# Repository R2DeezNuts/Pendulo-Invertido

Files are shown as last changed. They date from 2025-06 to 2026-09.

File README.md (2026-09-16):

# Péndulo invertido: control PID e interfaz web

Sistema de control PID para estabilizar un péndulo invertido con un ESP32. Incluye una interfaz web para ajustar los parámetros, telemetría y rutinas de calibración.

## Características

- Control PID a 100 Hz.
- Ajuste remoto de Kp, Ki, Kd, setpoint y offset.
- Calibración del ángulo cero.
- Desactivación automática cuando detecta una caída.
- Telemetría del estado del sistema.
- Anti-windup para limitar la acumulación del término integral.

## Hardware

- **Microcontrolador:** ESP32
- **Sensor inercial:** MPU6050 (acelerómetro y giroscopio)
- **Actuadores:** dos motores DC con puente H

### Conexiones GPIO

#### MPU6050 (I2C)

| Señal | GPIO |
|---:|:----:|
| SDA | 21 |
| SCL | 22 |

#### Motores (puente H)

| Motor | Señal | GPIO |
|---:|:-----:|
| A | PWMA  | 26 |
| A | AIN1  | 2 |
| A | AIN2  | 0 |
| B | PWMB  | 25 |
| B | BIN1  | 16 |
| B | BIN2  | 17 |

## Puesta en marcha

1. Conéctate a la red WiFi **RobotAP** (contraseña: 12345678).
2. Abre http://192.168.4.1 en el navegador.
3. Con el robot en posición vertical, calibra el ángulo cero antes de activar los motores.
4. Ajusta los parámetros PID desde la interfaz y activa el control.

Péndulo invertido en funcionamiento

## Parámetros ajustables

| Parámetro | Descripción |
|---:|---|
| **Kp, Ki, Kd** | Constantes del controlador PID |
| **Setpoint** | Ángulo objetivo, en grados |
| **Offset** | Ajuste fino para la calibración |

## Protección y arquitectura

La protección desactiva el control cuando el ángulo supera los 30° durante más de un segundo. El control se ejecuta en una tarea de FreeRTOS a 100 Hz; el servidor web permite consultar el estado y cambiar los parámetros; y un filtro complementario combina el acelerómetro y el giroscopio para estimar el ángulo.

## Uso recomendado

Coloca el robot en vertical, calibra el sensor y empieza con valores PID conservadores. Activa los motores mientras observas la telemetría y ajusta el setpoint y el offset de forma gradual.

Si entra en modo de protección, revisa la calibración, el sentido de giro, la saturación del control y las vibraciones o el ruido del MPU6050.

Detalle del péndulo invertido

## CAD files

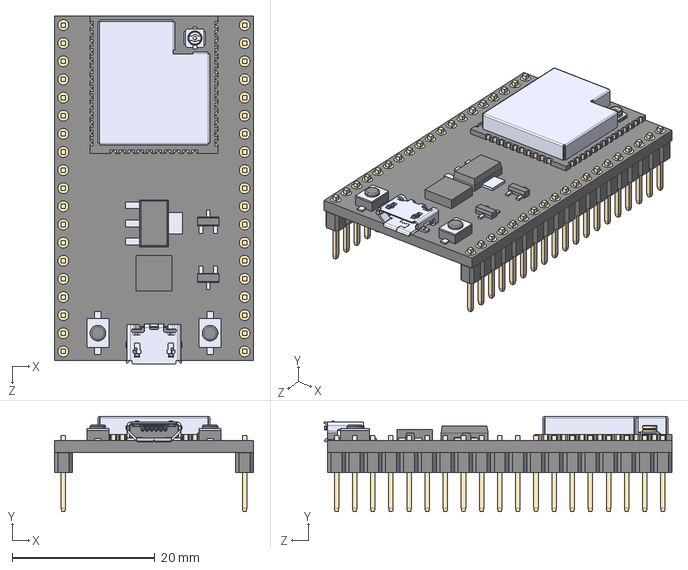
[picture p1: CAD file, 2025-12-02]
PCB/ESP32-DEVKITC-32UE/ESP32-DEVKITC-32UE.step
27.9 x 13.4 x 48.8 mm

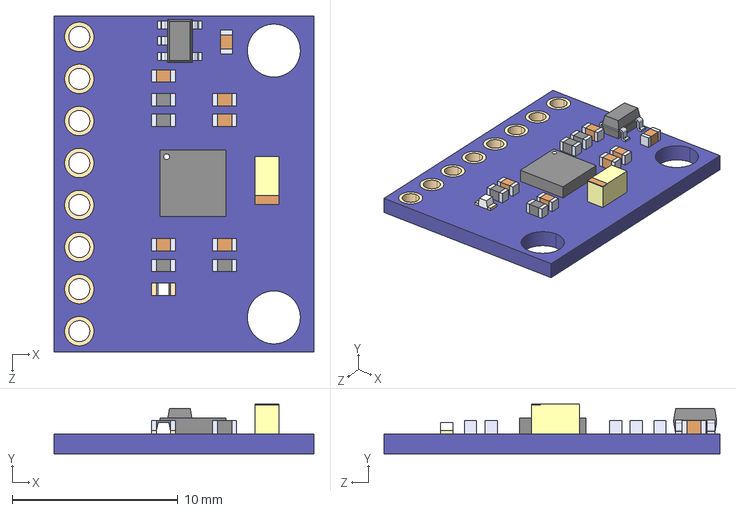
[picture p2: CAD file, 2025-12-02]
PCB/GY-521/GY-521.step
15.7 x 3.00 x 20.3 mm

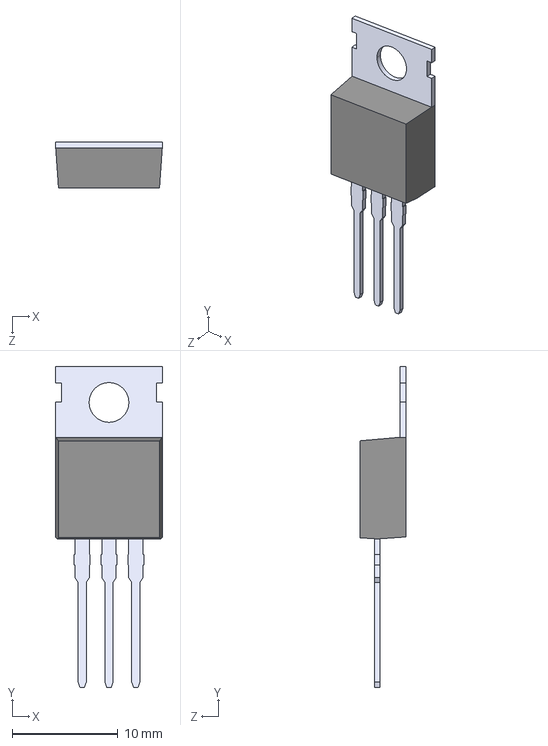
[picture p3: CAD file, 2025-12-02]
PCB/LM7805CT_NOPB.step
10.2 x 30.3 x 4.35 mm

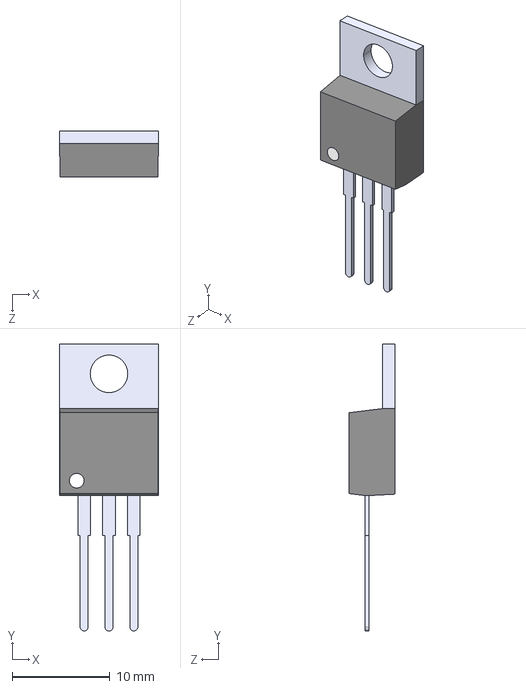
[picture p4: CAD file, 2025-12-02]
PCB/LM7805CT_NOPB/LM7805CT_NOPB.step
10.2 x 29.3 x 4.70 mm

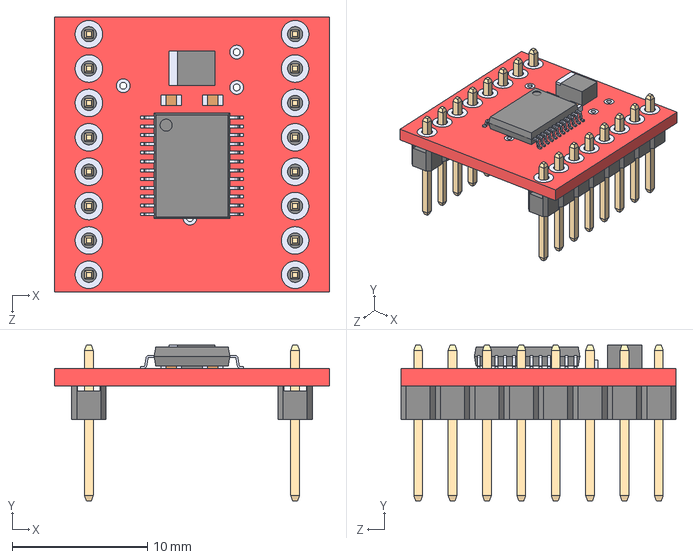
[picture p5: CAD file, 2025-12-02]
PCB/ROB-14450/ROB-14450.step
20.3 x 11.5 x 20.3 mm

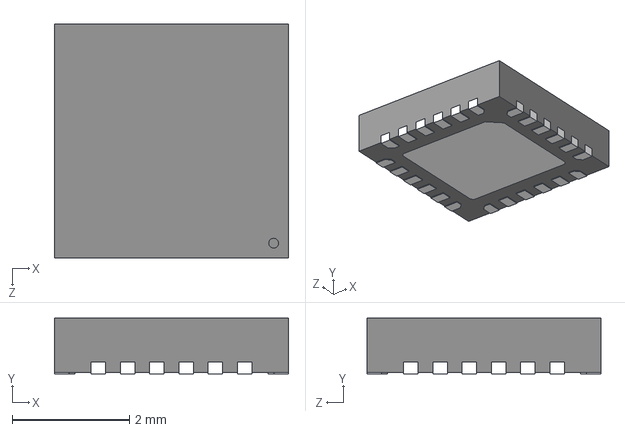
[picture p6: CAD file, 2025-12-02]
PCB/MPU-6050-A.step
4.00 x 0.95 x 4.00 mm

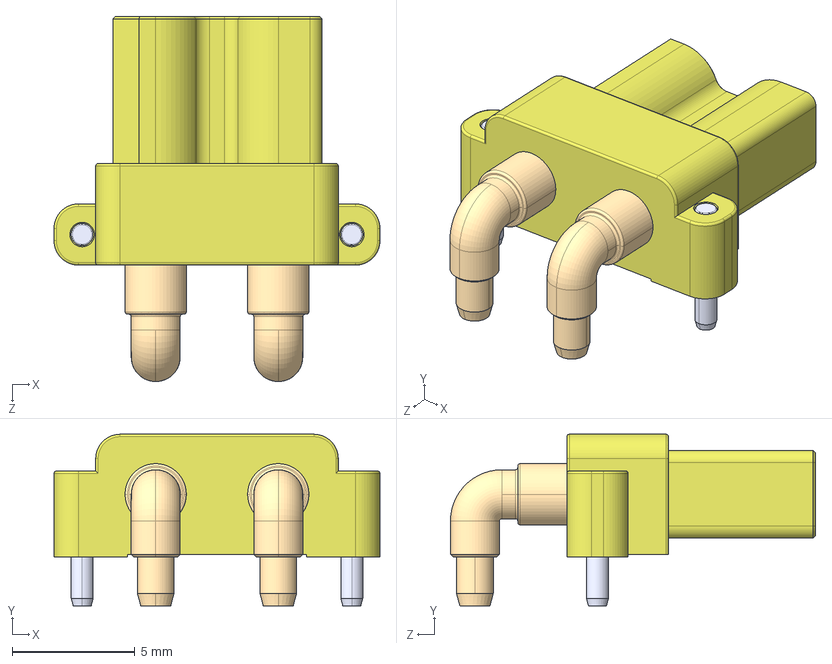
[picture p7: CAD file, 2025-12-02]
PCB/XT30PW-F.step
13.3 x 7.00 x 14.9 mm

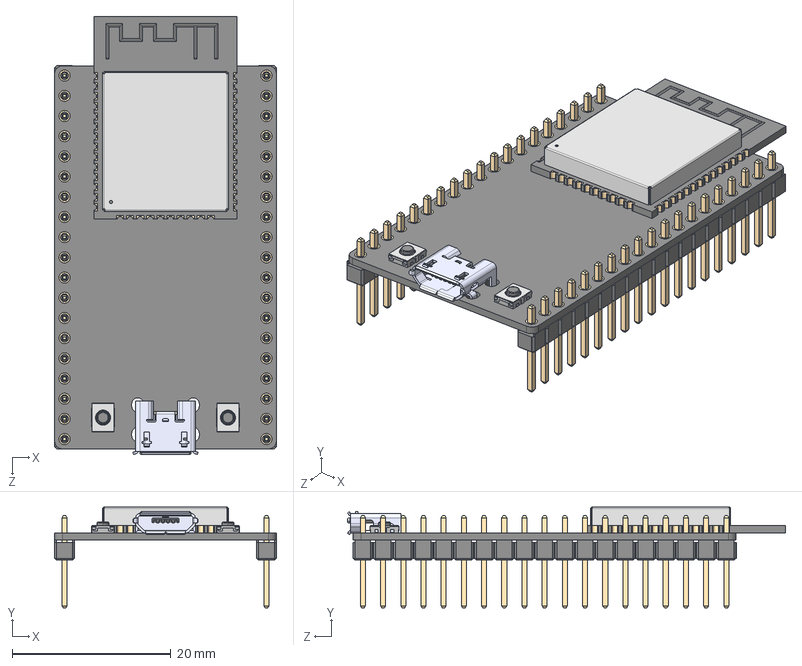
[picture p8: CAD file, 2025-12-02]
PCB/ESP32-DEVKITC-32D.step
27.9 x 12.7 x 55.1 mm
board
header x 2
ESP32-WROOM-32D
micro usb
button x 2

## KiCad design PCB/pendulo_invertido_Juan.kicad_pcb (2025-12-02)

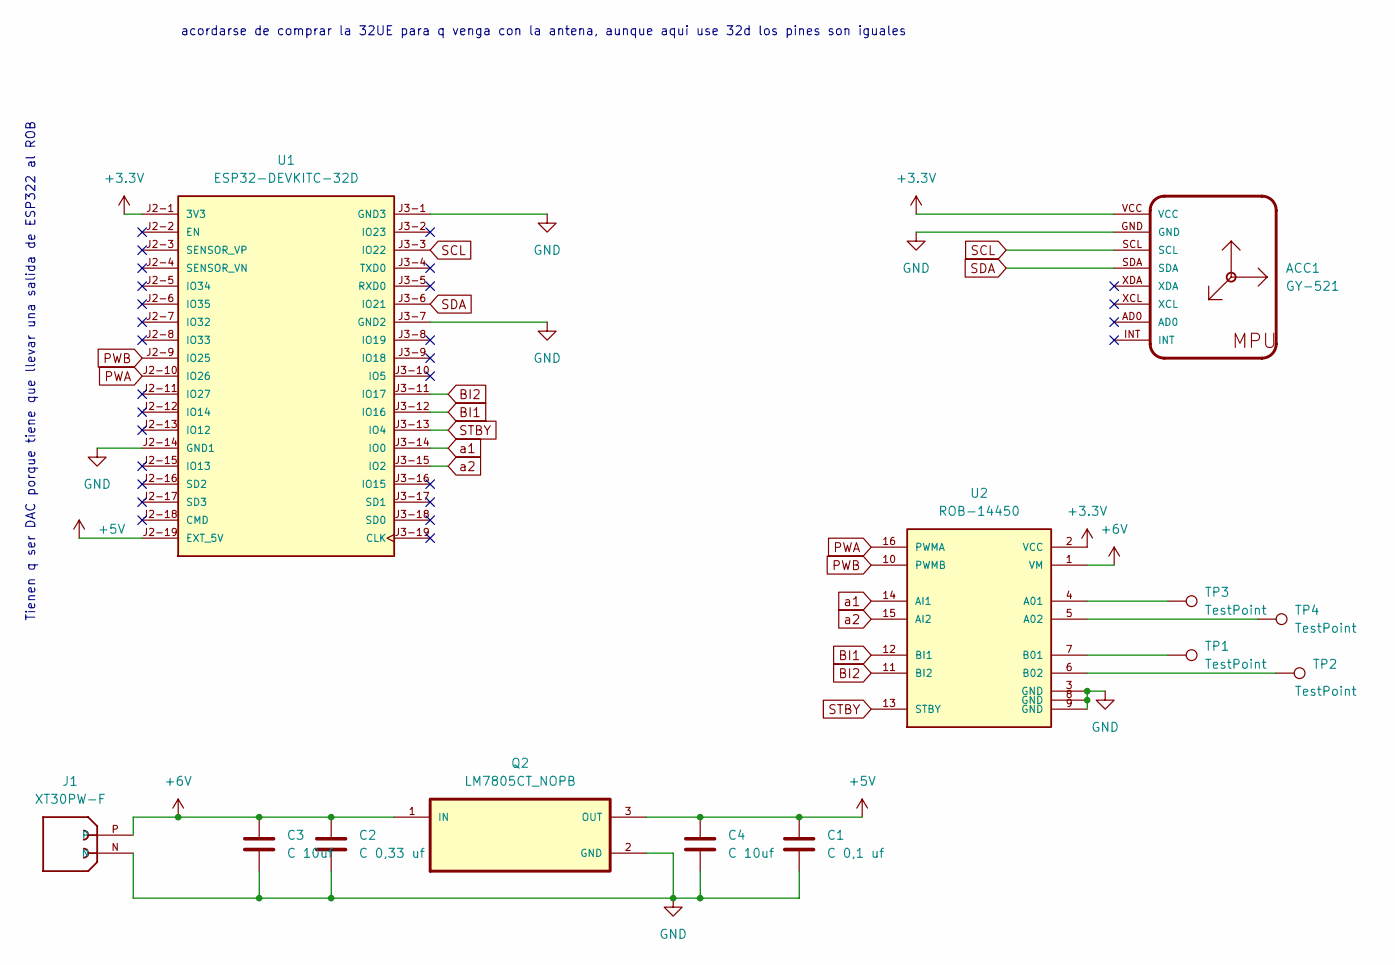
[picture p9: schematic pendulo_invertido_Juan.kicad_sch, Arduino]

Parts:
ACC1: GY-521
C1: C 0,1 uf; C_Disc_D4.3mm_W1.9mm_P5.00mm
C2: C 0,33 uf; C_Disc_D4.3mm_W1.9mm_P5.00mm
C3, C4: C 10uf; CP_Radial_D4.0mm_P2.00mm
J1: XT30PW-F; AMASS_XT30PW-F; PARTREV 1.2
Q2: LM7805CT_NOPB; TO254P1054X470X1955-3
TP1, TP2, TP3, TP4: TestPoint; TestPoint_THTPad_D2.0mm_Drill1.0mm
U1: ESP32-DEVKITC-32D; MODULE_ESP32-DEVKITC-32D; PARTREV V4
U2: ROB-14450; MODULE_ROB-14450; PARTREV 11-13-17

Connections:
+3.3V: ACC1.VCC, U1.J2-1 (3V3), U2.2 (VCC)
+5V: C1.1, C4.1, Q2.3 (OUT), U1.J2-19 (EXT_5V)
+6V: C2.1, C3.1, J1.P, Q2.1 (IN), U2.1 (VM)
BI1: U1.J3-12 (IO16), U2.12 (BI1)
BI2: U1.J3-11 (IO17), U2.11 (BI2)
GND: ACC1.GND, C1.2, C2.2, C3.2, C4.2, J1.N, Q2.2 (GND), U1.J2-14 (GND1), U1.J3-1 (GND3), U1.J3-7 (GND2), U2.3 (GND), U2.8 (GND), U2.9 (GND)
unnamed: TP3.1, U2.4 (A01)
unnamed: TP4.1, U2.5 (A02)
unnamed: TP1.1, U2.7 (B01)
unnamed: TP2.1, U2.6 (B02)
PWA: U1.J2-10 (IO26), U2.16 (PWMA)
PWB: U1.J2-9 (IO25), U2.10 (PWMB)
SCL: ACC1.SCL, U1.J3-3 (IO22)
SDA: ACC1.SDA, U1.J3-6 (IO21)
STBY: U1.J3-13 (IO4), U2.13 (STBY)
a1: U1.J3-14 (IO0), U2.14 (AI1)
a2: U1.J3-15 (IO2), U2.15 (AI2)

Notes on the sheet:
Tienen q ser DAC porque tiene que llevar una salida de ESP322 al ROB
acordarse de comprar la 32UE para q venga con la antena, aunque aqui use 32d los pines son iguales

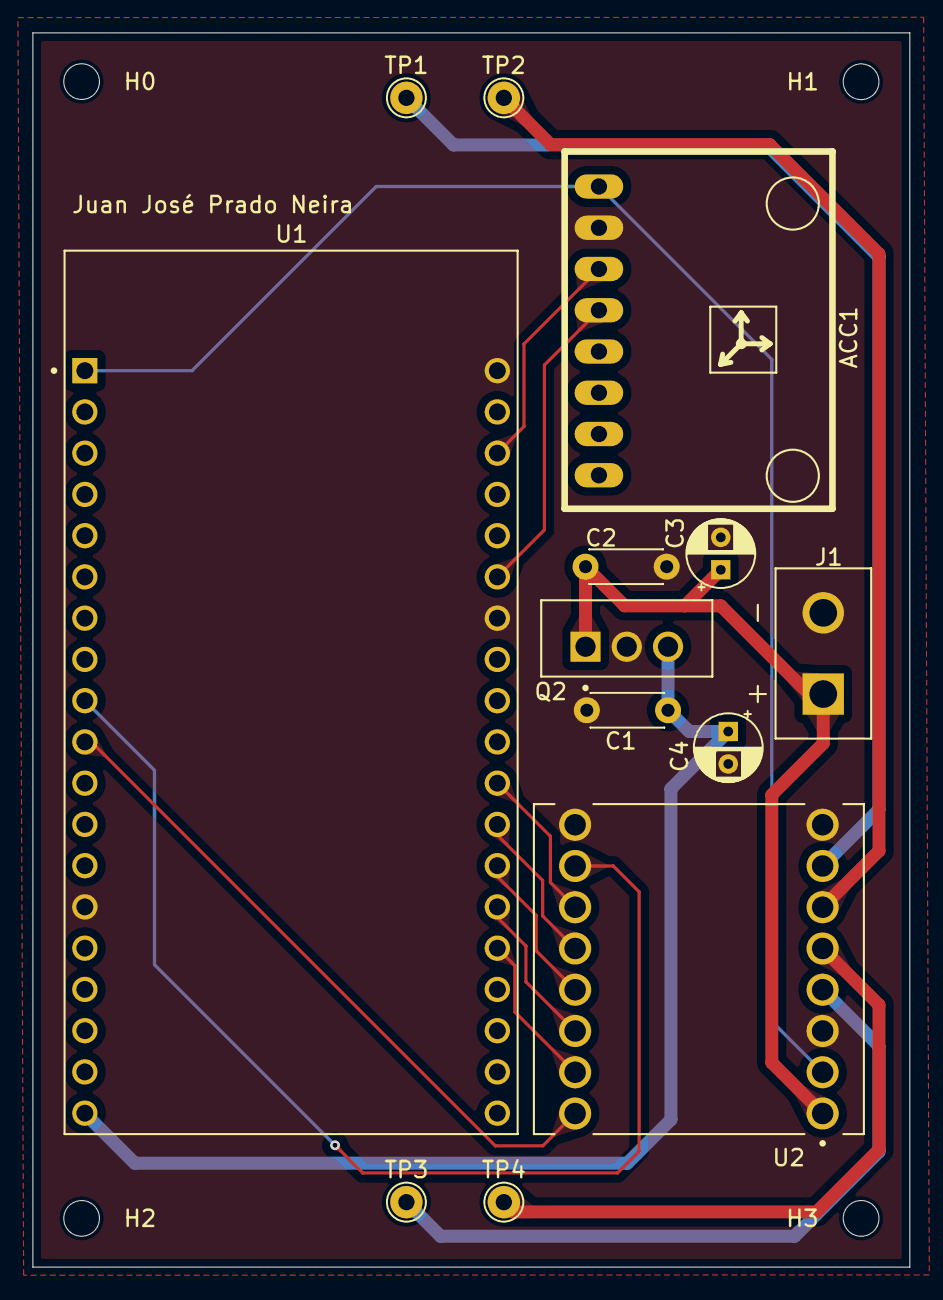
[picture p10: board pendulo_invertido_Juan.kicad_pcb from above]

Board: 2 copper layers, 54.0 x 76.0 mm, 17 parts (0 on the bottom side), 17 nets.

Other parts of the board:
H0, H1, H2, H3: MountingHole_2.2mm_M2

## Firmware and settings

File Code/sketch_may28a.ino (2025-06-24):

#include <Arduino.h>
#include <WiFi.h>
#include <WebServer.h>
#include <DNSServer.h>
#include <EEPROM.h>
#include "Wire.h"
#include "I2Cdev.h"
#include "MPU6050.h"

// --------- Pines Motores ------------
const int pinSTBY      = 4;
const int pinPWMA      = 26; // DERECHO
const int pinAIN1      = 2;  // DERECHO
const int pinAIN2      = 0;  // DERECHO
const int pinPWMB      = 25; // IZQUIERDO
const int pinBIN1      = 16; // IZQUIERDO
const int pinBIN2      = 17; // IZQUIERDO

// --------- Variables MPU y filtro ---------
MPU6050 mpu;
int16_t ax, ay, az, gx, gy, gz;
float ang_x = 0, ang_x_prev = 0, accel_ang_x = 0;
float dt = 0;
unsigned long calibrateTime = 0;
float ANGLE_OFFSET = 0;
const float alpha = 0.995;

// --------- PID ---------
double setpoint = 1.0;
double output = 0.0;
double Kp = 20.0, Ki = 0.3, Kd = 0.3;
double integral = 0.0, derivative = 0.0, previous_error = 0.0;

// --------- Anti-windup PID ---------
const double integral_max = 200;
const double integral_min = -200;

// --------- Seguridad (caída, autoparado) ---------
const float MAX_ANGLE = 30.0; // grados
const unsigned long FALL_TIMEOUT = 1000; // ms
unsigned long fallStartTime = 0;
bool fallen = false;

// --------- Control Task ---------
const unsigned long CONTROL_PERIOD_MS = 10; // 10ms = 100Hz
unsigned long lastControlTime = 0;

// --------- Estado motores ---------
bool motorsEnabled = false;

// --------- WiFi portal ---------
const char* ssid     = "RobotAP";
const char* password = "12345678";
IPAddress apIP(192, 168, 4, 1);
IPAddress netMsk(255, 255, 255, 0);
WebServer server(80);
DNSServer dnsServer;
const byte DNS_PORT = 53;

float loopFrequency = 0.0;
float ajuste_fino = 0.0;

// --------- EEPROM ---------
#define EEPROM_SIZE 32
#define ADDR_KP      0
#define ADDR_KI      4
#define ADDR_KD      8
#define ADDR_SETPT  12
#define ADDR_AJUSTE 16
#define ADDR_MAGIC  20
#define MAGIC_VALUE 0xAA55AA55

void saveParams() {
  EEPROM.put(ADDR_KP,      Kp);
  EEPROM.put(ADDR_KI,      Ki);
  EEPROM.put(ADDR_KD,      Kd);
  EEPROM.put(ADDR_SETPT,   setpoint);
  EEPROM.put(ADDR_AJUSTE,  ajuste_fino);
  EEPROM.put(ADDR_MAGIC,   MAGIC_VALUE);
  EEPROM.commit();
}

void loadParams() {
  uint32_t magic;
  EEPROM.get(ADDR_MAGIC, magic);
  if (magic == MAGIC_VALUE) {
    EEPROM.get(ADDR_KP,      Kp);
    EEPROM.get(ADDR_KI,      Ki);
    EEPROM.get(ADDR_KD,      Kd);
    EEPROM.get(ADDR_SETPT,   setpoint);
    EEPROM.get(ADDR_AJUSTE,  ajuste_fino);
    Serial.println("Parámetros PID cargados de EEPROM.");
  } else {
    Serial.println("EEPROM no inicializada, usando valores por defecto.");
  }
}

// --------- Prototipos ---------
void handleRoot();
void handleToggle();
void handleStatus();
void handleGetSettings();
void handleSetSettings();
void handleNotFound();
void handleCalibrate();
void setupWiFiPortal();
void driveMotors(int value);
void ControlTask(void * parameter);

// --------- Motores ------------
void driveMotors(int value) {
  value = constrain(value, -255, 255);
  int mag = abs(value);

  // Motor IZQUIERDO (PWMB, BIN1, BIN2)
  if (value > 0) {
    digitalWrite(pinBIN1, HIGH); digitalWrite(pinBIN2, LOW); // Adelante
  } else if (value < 0) {
    digitalWrite(pinBIN1, LOW); digitalWrite(pinBIN2, HIGH); // Atrás
  } else {
    digitalWrite(pinBIN1, HIGH); digitalWrite(pinBIN2, HIGH);
    mag = 0;
  }
  analogWrite(pinPWMB, mag);

  // Motor DERECHO (PWMA, AIN1, AIN2)
  if (value > 0) {
    digitalWrite(pinAIN1, HIGH); digitalWrite(pinAIN2, LOW); // Adelante
  } else if (value < 0) {
    digitalWrite(pinAIN1, LOW); digitalWrite(pinAIN2, HIGH); // Atrás
  } else {
    digitalWrite(pinAIN1, HIGH); digitalWrite(pinAIN2, HIGH);
    mag = 0;
  }
  analogWrite(pinPWMA, mag);
}

// --------- Handlers web ---------
void handleRoot() {
  String html = R"rawliteral(
<!DOCTYPE html>
<html>
<head>
  <meta name="viewport" content="width=device-width, initial-scale=1">
  <style>
    body { margin:0; display:flex; flex-direction:column; justify-content:center; align-items:center; height:100vh; background:#000; color:#fff; }
    button, input { font-size:1.2em; margin:5px; }
    button { padding:10px; border:none; border-radius:5px; width:80%; height:40px; }
    .on { background:#4CAF50; color:#fff; }
    .off { background:#F44336; color:#fff; }
    #controls { margin-top:20px; display:flex; flex-direction:column; align-items:center; }
    label { display:flex; justify-content:space-between; width:80%; }
    input { width:60px; }
  </style>
</head>
<body>
  <button id="btn" class="off">OFF</button>
  <button id="calibrate">Calibrar ángulo cero</button>
  <div id="status">Cargando...</div>
  <div id="controls">
    <label>Kp: <input id="Kp" type="number" step="0.1"></label>
    <label>Ki: <input id="Ki" type="number" step="0.01"></label>
    <label>Kd: <input id="Kd" type="number" step="0.1"></label>
    <label>Setpoint: <input id="Setpoint" type="number" step="0.1"></label>
    <label>Ajuste fino: <input id="Ajuste" type="number" step="0.01"></label>
    <button id="apply">Aplicar</button>
  </div>
  <script>
    const btn = document.getElementById('btn');
    const status = document.getElementById('status');
    const inpKp = document.getElementById('Kp');
    const inpKi = document.getElementById('Ki');
    const inpKd = document.getElementById('Kd');
    const inpSetpoint = document.getElementById('Setpoint');
    const inpAjuste = document.getElementById('Ajuste');
    const calibrate = document.getElementById('calibrate');

    function updateButton(s) { btn.textContent = s; btn.className = s.toLowerCase(); }
    btn.onclick = () => fetch('/toggle').then(r => r.text()).then(updateButton);

    calibrate.onclick = () => { fetch('/calibrate').then(r => r.text()).then(alert); };

    function updateStatus() {
      fetch('/status').then(r => r.text()).then(t => status.textContent = t);
    }
    setInterval(updateStatus, 500); updateStatus();

    fetch('/getsettings').then(r => r.json()).then(j => {
      inpKp.value = j.Kp;
      inpKi.value = j.Ki;
      inpKd.value = j.Kd;
      inpSetpoint.value = j.Setpoint;
      inpAjuste.value = j.Ajuste;
    });

    document.getElementById('apply').onclick = () => {
      const p = new URLSearchParams({
        Kp: inpKp.value,
        Ki: inpKi.value,
        Kd: inpKd.value,
        Setpoint: inpSetpoint.value,
        Ajuste: inpAjuste.value
      });
      fetch('/setsettings?' + p).then(r => r.text()).then(alert);
    };
  </script>
</body>
</html>
)rawliteral";
  server.send(200, "text/html", html);
}

void handleToggle() {
  bool prevMotorsEnabled = motorsEnabled;
  motorsEnabled = !motorsEnabled;
  // Si se acaba de activar, resetea PID:
  if (motorsEnabled && !prevMotorsEnabled) {
    integral = 0;
    derivative = 0;
    previous_error = 0;
  }
  server.send(200, "text/plain", motorsEnabled?"ON":"OFF");
}
void handleStatus() {
  String stat = String(motorsEnabled ? "ON" : "OFF") +
                (fallen ? " | CAIDO" : "") +
                " | Ángulo: " + String(ang_x, 2) +
                "° | Velocidad: " + String(abs(output), 0) +
                " | Loop: " + String(loopFrequency, 1) + " Hz";
  server.send(200, "text/plain", stat);
}
void handleGetSettings() {
  String json = String("{\"Kp\":") + String(Kp,2) + ",\"Ki\":" + String(Ki,2) +
                ",\"Kd\":" + String(Kd,2) + ",\"Setpoint\":" + String(setpoint,2) +
                ",\"Ajuste\":" + String(ajuste_fino,2) + "}";
  server.send(200, "application/json", json);
}
void handleSetSettings() {
  if (server.hasArg("Kp")) Kp = server.arg("Kp").toFloat();
  if (server.hasArg("Ki")) Ki = server.arg("Ki").toFloat();
  if (server.hasArg("Kd")) Kd = server.arg("Kd").toFloat();
  if (server.hasArg("Setpoint")) setpoint = server.arg("Setpoint").toFloat();
  if (server.hasArg("Ajuste")) ajuste_fino = server.arg("Ajuste").toFloat();
  saveParams();
  server.send(200, "text/plain", "Settings updated");
}
void handleNotFound() {
  server.sendHeader("Location", String("http://") + apIP.toString(), true);
  server.send(302, "text/plain", "");
}
void handleCalibrate() {
  float sum = 0;
  int N = 100;
  for (int i = 0; i < N; i++) {
    mpu.getAcceleration(&ax, &ay, &az);
    sum += atan2(ay, az) * 180.0 / PI;
    delay(5);
  }
  ANGLE_OFFSET = sum / N;
  mpu.getAcceleration(&ax, &ay, &az);
  ang_x = ang_x_prev = atan2(ay, az) * 180.0 / PI - ANGLE_OFFSET - ajuste_fino;
  integral = 0;
  derivative = 0;
  previous_error = 0;
  calibrateTime = millis();
  fallen = false;
  Serial.print("Nuevo OFFSET calculado: "); Serial.println(ANGLE_OFFSET, 2);
  server.send(200, "text/plain", "Offset calibrado. ¡Ya puedes encender los motores!");
}

void setupWiFiPortal() {
  WiFi.mode(WIFI_AP);
  WiFi.softAPConfig(apIP, apIP, netMsk);
  WiFi.softAP(ssid, password);
  dnsServer.start(DNS_PORT, "*", apIP);
  server.on("/", handleRoot);
  server.on("/toggle", handleToggle);
  server.on("/status", handleStatus);
  server.on("/getsettings", handleGetSettings);
  server.on("/setsettings", handleSetSettings);
  server.on("/calibrate", handleCalibrate);
  server.onNotFound(handleNotFound);
  server.begin();
  Serial.print("AP iniciado en: "); Serial.println(WiFi.softAPIP());
}

void setup() {
  Serial.begin(115200);
  delay(2000);

  pinMode(pinSTBY, OUTPUT);
  pinMode(pinAIN1, OUTPUT);
  pinMode(pinAIN2, OUTPUT);
  pinMode(pinBIN1, OUTPUT);
  pinMode(pinBIN2, OUTPUT);
  pinMode(pinPWMA, OUTPUT);
  pinMode(pinPWMB, OUTPUT);

  digitalWrite(pinSTBY, HIGH);

  Wire.begin();
  mpu.initialize();

  // === OFFSET CALIBRADOS MANUALMENTE ===
  mpu.setXAccelOffset(-3554);
  mpu.setYAccelOffset(5858);
  mpu.setZAccelOffset(10188);
  mpu.setXGyroOffset(-30);
  mpu.setYGyroOffset(-234);
  mpu.setZGyroOffset(-30);

  delay(1000);

  float sum = 0;
  int N = 100;
  for (int i = 0; i < N; i++) {
    mpu.getAcceleration(&ax, &ay, &az);
    sum += atan2(ay, az) * 180.0 / PI;
    delay(5);
  }
  ANGLE_OFFSET = sum / N;
  Serial.print("OFFSET calculado: "); Serial.println(ANGLE_OFFSET, 2);

  mpu.getAcceleration(&ax, &ay, &az);
  ang_x = ang_x_prev = atan2(ay, az) * 180.0 / PI - ANGLE_OFFSET;
  calibrateTime = millis();
  lastControlTime = millis();

  EEPROM.begin(EEPROM_SIZE);
  loadParams();

  setupWiFiPortal();

  // --- Iniciar la tarea de control en FreeRTOS ---
  xTaskCreatePinnedToCore(
    ControlTask,
    "ControlTask",
    4096,
    NULL,
    2,
    NULL,
    1
  );
}

void loop() {
  dnsServer.processNextRequest();
  server.handleClient();
}

// ----- Tarea de control PID, filtro, autoparado, motores -----
void ControlTask(void * parameter) {
  unsigned long lastPrint = 0;
  lastControlTime = millis();
  while (true) {
    unsigned long now = millis();
    if (now - lastControlTime >= CONTROL_PERIOD_MS) {
      dt = (now - lastControlTime) / 1000.0;
      lastControlTime = now;

      // --- Sensor MPU6050 ---
      int16_t ax_raw, ay_raw, az_raw, gx_raw, gy_raw, gz_raw;
      mpu.getAcceleration(&ax_raw, &ay_raw, &az_raw);
      mpu.getRotation(&gx_raw, &gy_raw, &gz_raw);

      // --- Remapeo de ejes ---
      ax = -ay_raw;
      ay =  ax_raw;
      az =  az_raw;
      gx = -gy_raw;
      gy =  gx_raw;
      gz =  gz_raw;

      // --- Filtro complementario ---
      accel_ang_x = atan2(ay, az) * 180.0 / PI - ANGLE_OFFSET - ajuste_fino;

      if (now - calibrateTime < 2000) {
        ang_x = ang_x_prev = accel_ang_x;
      } else {
        float gyro_rate = gx / 131.0;
        ang_x = alpha * (ang_x_prev + gyro_rate * dt) + (1 - alpha) * accel_ang_x;
        ang_x_prev = ang_x;
      }

      // --- Autoparado ---
      if (abs(ang_x) > MAX_ANGLE) {
        if (fallStartTime == 0) fallStartTime = now;
        if (!fallen && now - fallStartTime > FALL_TIMEOUT) {
          fallen = true;
          motorsEnabled = false;
          Serial.println("Robot caído: motores deshabilitados.");
          integral = 0;
          derivative = 0;
          previous_error = 0;
        }
      } else {
        fallStartTime = 0;
        fallen = false;
      }

      // --- PID ---
      double error = setpoint - ang_x;
      integral += error * dt;
      if (integral > integral_max) integral = integral_max;
      if (integral < integral_min) integral = integral_min;
      derivative = (error - previous_error) / dt;
      output = Kp * error + Ki * integral + Kd * derivative;
      previous_error = error;

      // --- Motores ---
      if (motorsEnabled) {
        digitalWrite(pinSTBY, HIGH);
        driveMotors(-(int)output);
      } else {
        driveMotors(0);
        digitalWrite(pinSTBY, LOW);
      }

      // --- Frecuencia real de loop ---
      loopFrequency = 1.0 / dt;

      // --- Log serie cada 100 ms ---
      if (now - lastPrint > 100) {
        Serial.print("Ángulo: "); Serial.print(ang_x, 2);
        Serial.print(", PID: "); Serial.print(output, 2);
        Serial.print(", Offset: "); Serial.print(ANGLE_OFFSET, 2);
        Serial.print(", Setpoint: "); Serial.println(setpoint, 2);
        lastPrint = now;
      }
    }
    vTaskDelay(1); // Cede la CPU a otras tareas
  }
}
